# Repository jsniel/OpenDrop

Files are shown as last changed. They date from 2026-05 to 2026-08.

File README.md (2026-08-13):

# OpenDrop

**Low-power wireless irrigation controller**

Open-source autonomous irrigation controller based on an ESP32-C3 Mini.

---

## Description

OpenDrop is a low-power irrigation controller designed for small-scale market gardening and drip irrigation systems.

Originally created to replace manual irrigation valves, it automates watering schedules and reduces repetitive daily work.

Designed for remote plots without access to mains electricity, OpenDrop runs on battery power using deep sleep and pulse-operated latching valves.

The entire project is open-source:

- firmware;
- hardware;
- enclosure;
- wiring;
- documentation.

---

##  Features

- RTC-based irrigation scheduling
- Deep sleep low-power operation
- Local Wi‑Fi configuration portal
- Battery-powered operation
- Relay-controlled irrigation valve
- Configurable watering duration
- Configurable watering cycles
- EEPROM configuration storage
- Fully hackable firmware
- No cloud required

---

## Hardware

### Required

- ESP32-C3 Mini
- DS3231 RTC module
- 2-channel relay module
- MT3608 boost converter
- 18650 Li-ion battery
- AZ Delivery Battery Expansion Shield 18650
- Pulse-operated latching solenoid valve (+5V / -5V polarity reversal)
- 2 push buttons
- LED + resistor
- 1N4007 diode
- 1000 uF capacitors

---

## Wiring

<p align="center">
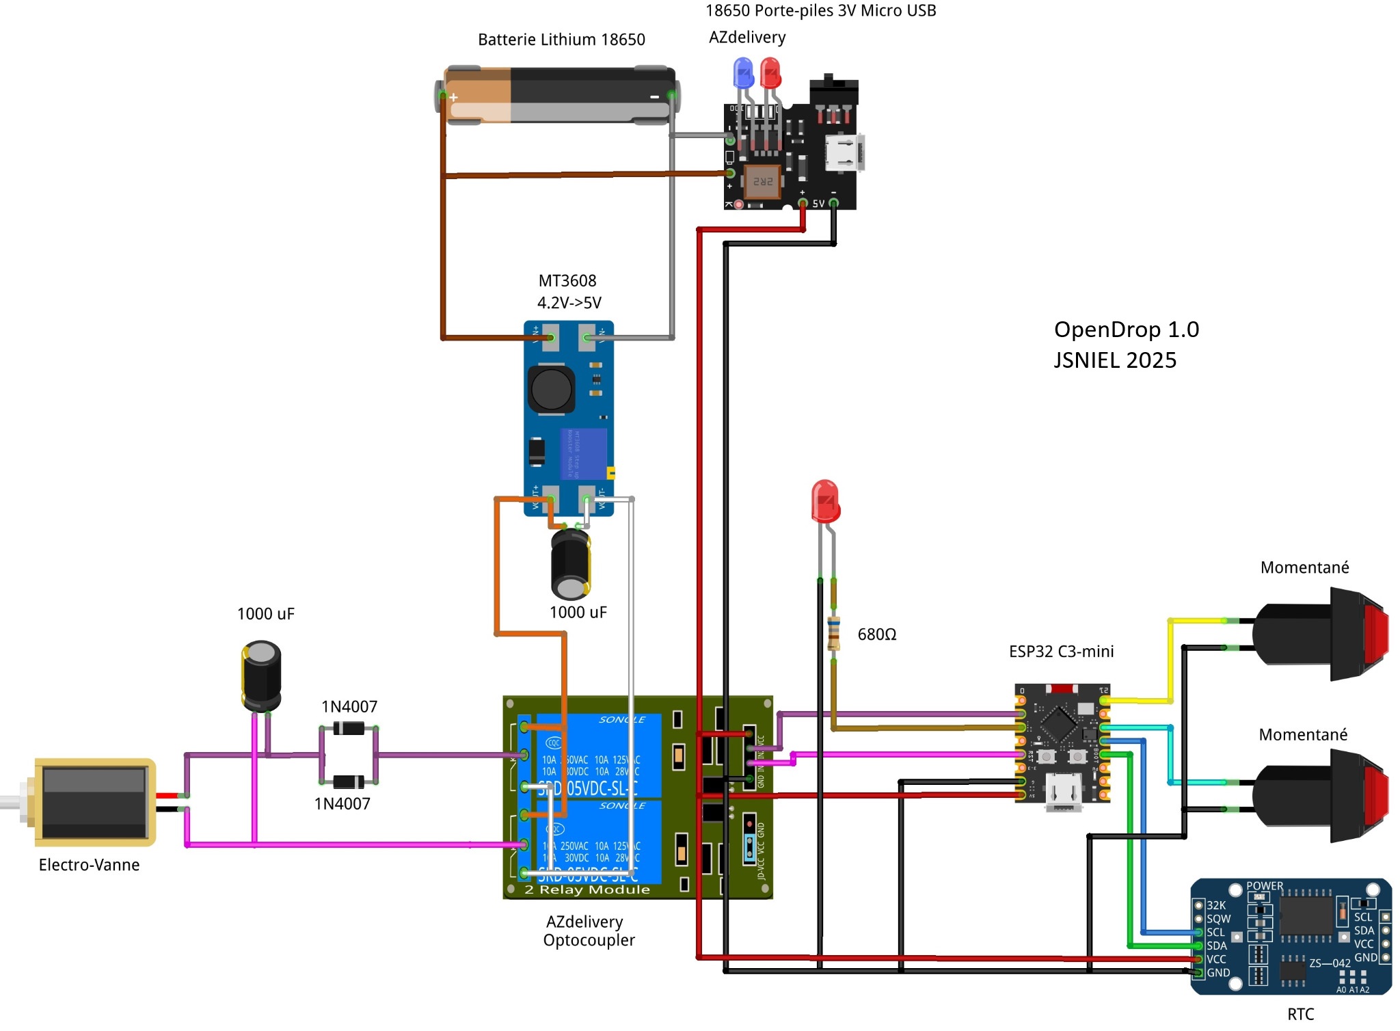
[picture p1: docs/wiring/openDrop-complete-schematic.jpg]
  
</p>
<p align="center">
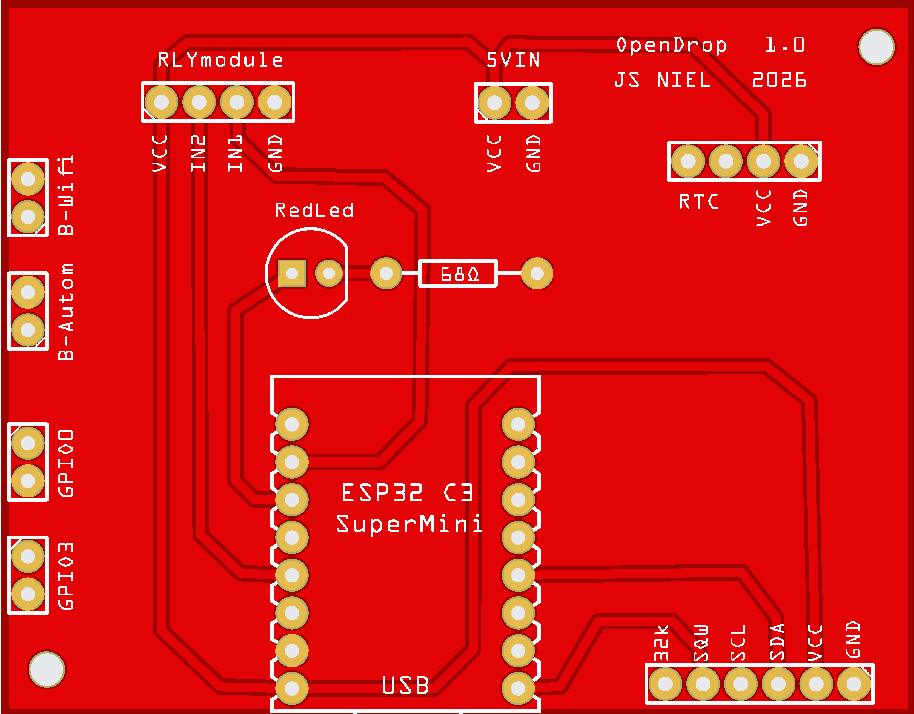
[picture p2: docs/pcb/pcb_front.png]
  
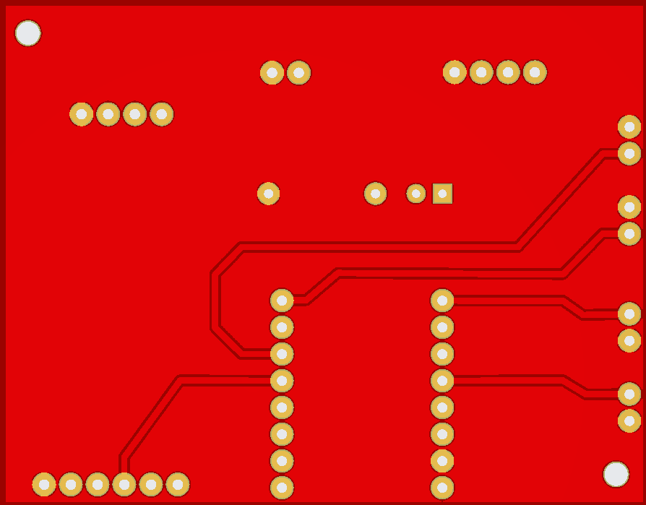
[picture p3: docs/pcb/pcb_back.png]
  
</p>

---

## Prototype Photos

<p align="center">
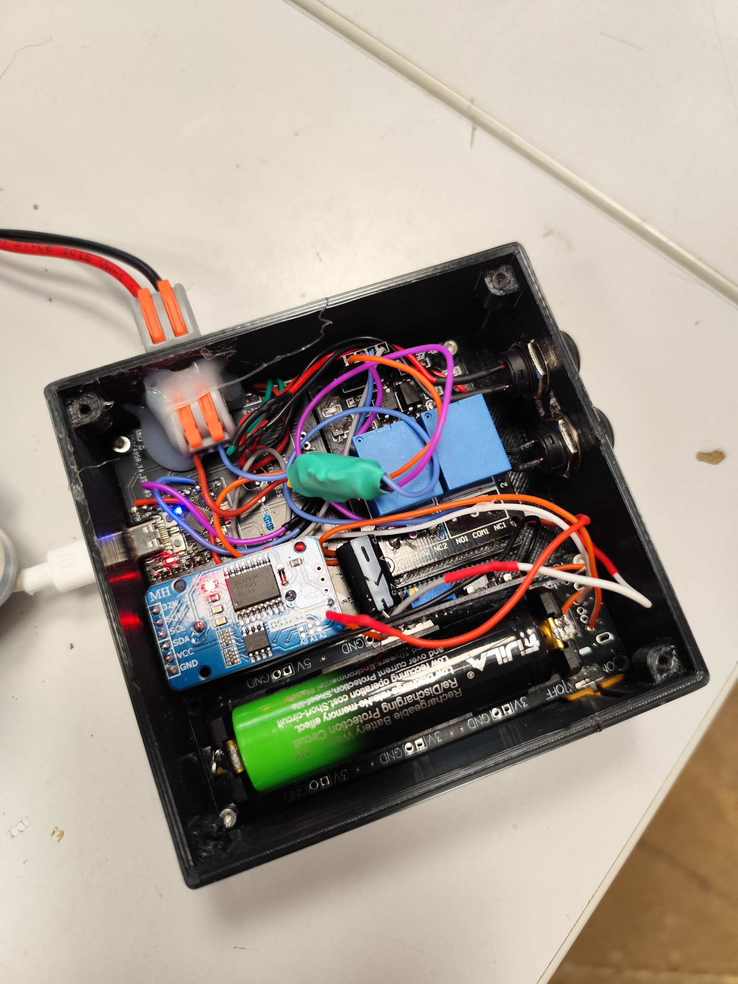
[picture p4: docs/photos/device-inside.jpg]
  
</p>
<p align="center">
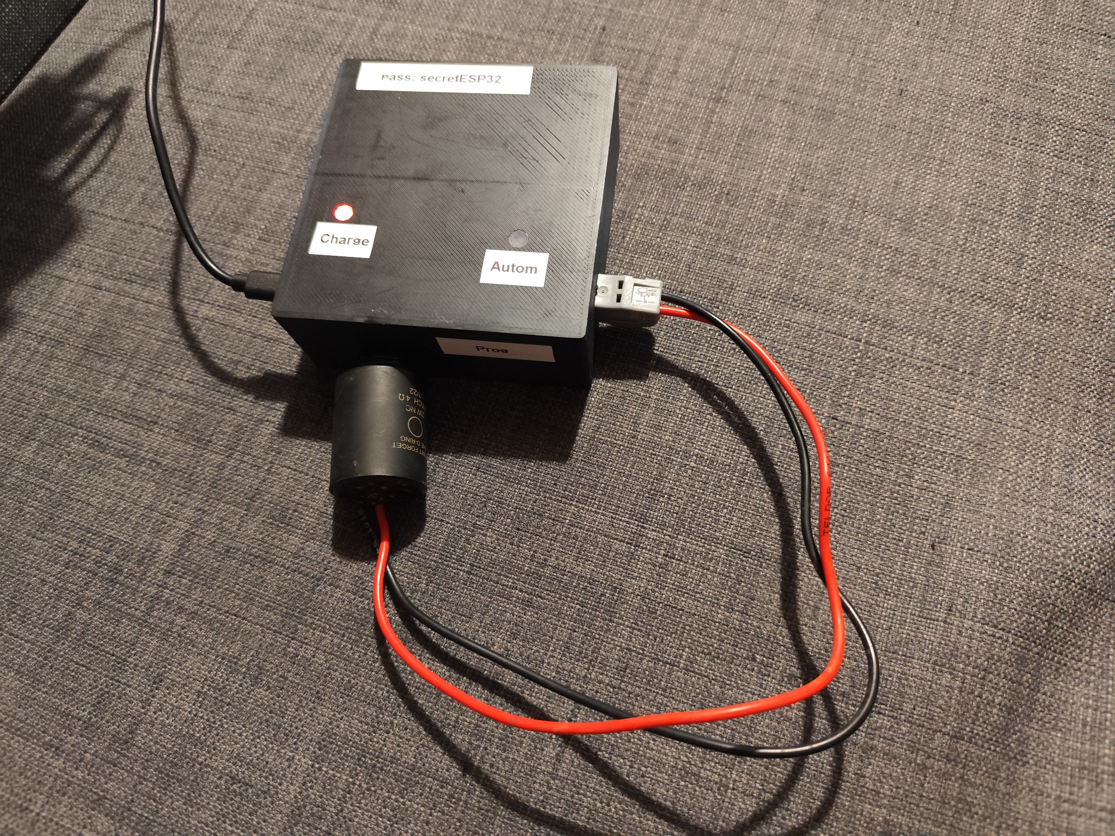
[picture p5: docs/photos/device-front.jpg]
  
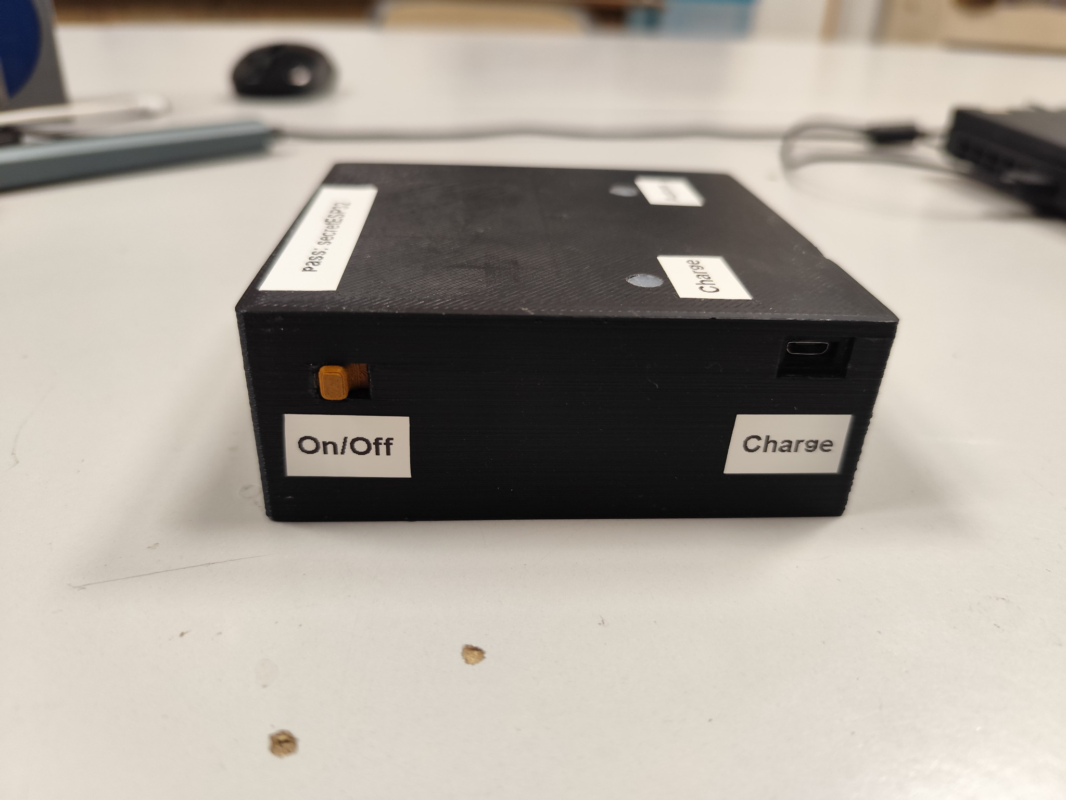
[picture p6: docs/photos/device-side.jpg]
  
</p>

---

## Web Interface

You can:

- Enable or disable automatic watering
- Configure watering time range
- Configure watering duration
- Configure watering cycles per day
- Set RTC time
- Put the controller back to sleep

<p align="center">
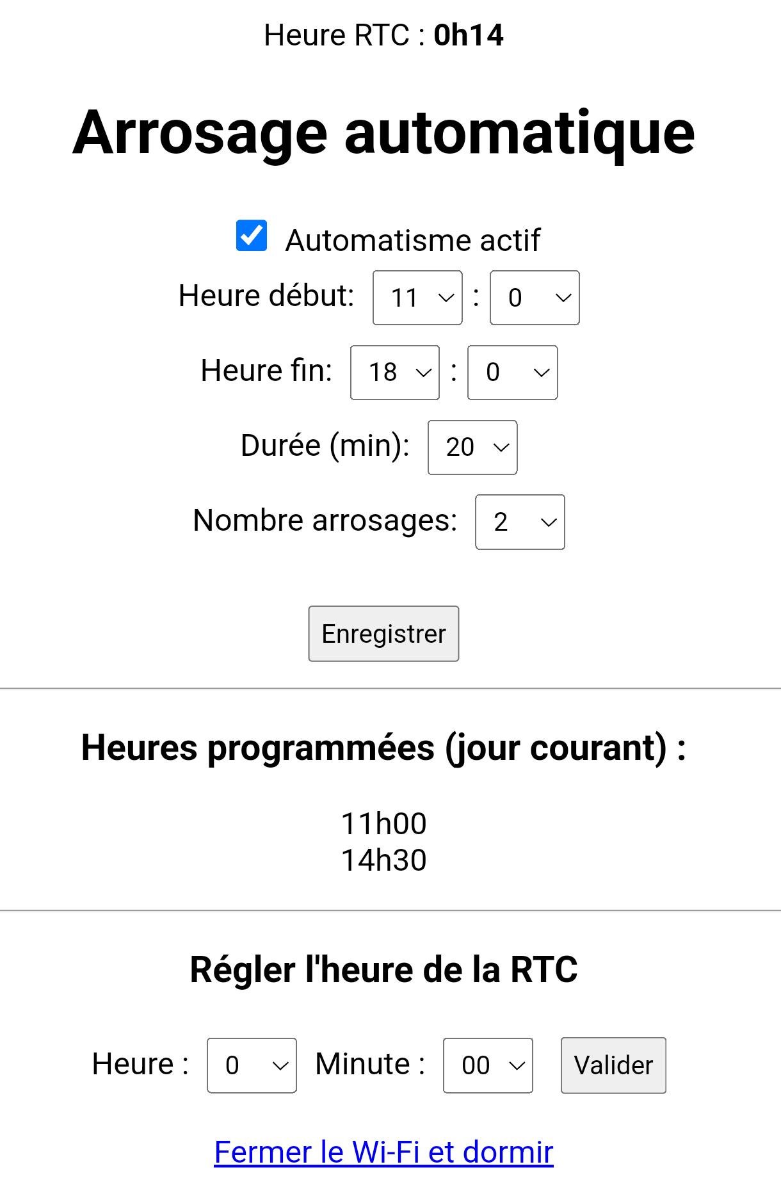
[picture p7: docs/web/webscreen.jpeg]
  
</p>

---

## Buttons and LED

### Wi‑Fi Button

Hold the Wi‑Fi button during wake-up to enable the local Wi‑Fi configuration portal.

Default configuration:

```txt
SSID: arrosageESP
Password: secretESP32
Address: http://192.168.4.1
```

The portal automatically closes after 5 minutes.

---

### Automation Button

Hold the automation button during wake-up to toggle automatic watering ON or OFF.

The state is saved in EEPROM.

---

### LED Behavior

| LED behavior | Meaning |
|---|---|
| Solid ON | Valve open |
| Two short blinks | Automation enabled |
| One long blink | Automation disabled |
| Slow blinking | Wi‑Fi portal active |
| OFF | Deep sleep mode |

---

## Firmware

Location:

```txt
firmware/OpenDrop/OpenDropFW/OpenDropFW.ino
```

---

## Arduino IDE Setup (ESP32‑C3)

### 1. Add ESP32 boards

Open Arduino IDE:

- Go to **File → Preferences**
- In **Additional Boards Manager URLs**, add:

```txt
https://raw.githubusercontent.com/espressif/arduino-esp32/gh-pages/package_esp32_index.json
```

---

### 2. Install ESP32 package

- Go to **Tools → Board → Boards Manager**
- Search: `esp32`
- Install:

```txt
esp32 by Espressif Systems
```

Tested version:

```txt
3.3.5
```

---

### 3. Select board

- Tools → Board → ESP32 Arduino
- Select:

```txt
ESP32C3 Dev Module
```

---

### 4. Required libraries

Install from Arduino Library Manager:

| Library | Tested version |
|---|---:|
| RTClib by Adafruit | 2.1.4 |
| Adafruit BusIO | 1.17.4 |

---

## Usage

### First boot

- Power the device
- Hold the Wi‑Fi button during wake-up
- Connect to the Wi‑Fi access point

---

### Connect

```txt
SSID: arrosageESP
Password: secretESP32
```

Open in browser:

```txt
http://192.168.4.1
```

---

## Known Issues

- No battery level monitoring
- Prototype enclosure is not fully waterproof
- No authentication on the web interface
- No OTA firmware update system

---

## Project Structure

```txt
OpenDrop/
├── firmware/
├── hardware/
├── enclosure/
├── docs/
├── LICENSES/
├── README.md
└── LICENSE
```

---

## Author

**Jean-Sébastien Niel**

GitHub:
https://github.com/jsniel

---

## License

OpenDrop uses separate licenses for firmware and hardware.

### Firmware

GNU General Public License v3.0 or later

```txt
GPL-3.0-or-later
```

### Hardware

CERN Open Hardware Licence Version 2 - Strongly Reciprocal

```txt
CERN-OHL-S-2.0
```

---

## ⚠️ Disclaimer

This project is an experimental DIY open hardware prototype.

OpenDrop switches electrical loads and may be used near water.

Always:

- verify wiring;
- protect electronics from humidity;
- use waterproof connectors;
- verify valve voltage compatibility;
- use appropriate battery protection.

This project is provided without warranty.

---

## Contributing

Pull requests and hardware improvements are welcome.

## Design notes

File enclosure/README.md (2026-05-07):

# Enclosure

3D printable enclosure files for OpenDrop.

Files:
- BOITIER-BOITE.stl
- BOITIER-COUVERCLE.stl
- Switch.stl
- BOITIER.FCStd

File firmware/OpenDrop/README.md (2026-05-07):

# OpenDrop firmware

ESP32-C3 firmware for the OpenDrop low-power wireless irrigation controller.

Firmware by Jean-Sébastien Niel.  
GitHub: https://github.com/jsniel

License: GPL-3.0-or-later

---

## Arduino IDE setup

### 1. Add ESP32 board support

Open Arduino IDE settings or preferences.

Add this URL to **Additional Boards Manager URLs**:

```txt
https://raw.githubusercontent.com/espressif/arduino-esp32/gh-pages/package_esp32_index.json
```

---

### 2. Install ESP32 board package

Open:

```txt
Tools → Board → Boards Manager
```

Search for:

```txt
esp32
```

Install:

```txt
esp32 by Espressif Systems
```

Tested version:

```txt
3.3.5
```

---

### 3. Select board

Select:

```txt
ESP32C3 Dev Module
```

---

## Required libraries

Install from the Arduino Library Manager:

| Library | Tested version | Notes |
|---|---:|---|
| RTClib by Adafruit | 2.1.4 | DS3231 RTC support |
| Adafruit BusIO | 1.17.4 | RTClib dependency |

See also:

```txt
libraries.txt
```

---

## Default access point

```txt
SSID: arrosageESP
Password: secretESP32
IP address: 192.168.4.1
```

Open:

```txt
http://192.168.4.1
```

---

## Buttons

### Wi-Fi button

GPIO: `GPIO10`

Holding the button during wake-up starts the Wi-Fi configuration portal for 5 minutes.

### Automation button

GPIO: `GPIO21`

Holding the button during wake-up toggles automatic watering ON or OFF.

The setting is saved in EEPROM.

If automation is disabled while watering is active, the valve is immediately closed.

---

## LED behavior

| LED behavior | Meaning |
|---|---|
| Solid ON | Valve open |
| Two short blinks | Automation enabled |
| One long blink | Automation disabled |
| Slow blinking | Wi-Fi portal active |
| OFF | Deep sleep |

The LED is configured as active-LOW.

The firmware disables the LED pin before deep sleep to minimize current consumption.

---

## Pin mapping

| Function | GPIO |
|---|---:|
| Wi-Fi mode button | 10 |
| Automation toggle button | 21 |
| Relay open | 4 |
| Relay close | 1 |
| LED | 2 |
| SDA | 8 |
| SCL | 9 |

---

## Deep sleep behavior

Default values in the firmware:

```txt
Button polling interval: 10 seconds
Web configuration window: 5 minutes
Relay pulse duration: 200 ms
```

---

## Web interface routes

| Route | Description |
|---|---|
| `/` | Main configuration page |
| `/save` | Save watering settings |
| `/setrtc` | Set RTC time |
| `/sleep` | Stop Wi-Fi and return to sleep |

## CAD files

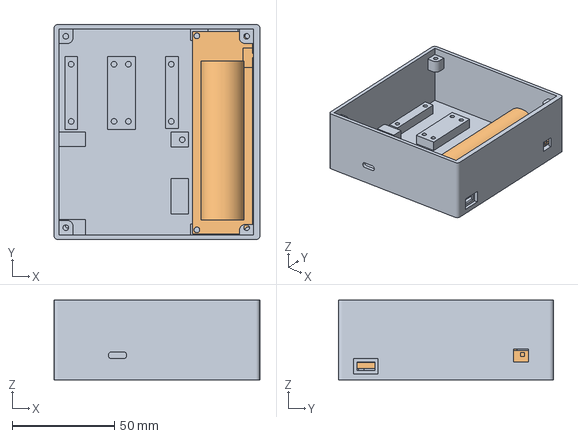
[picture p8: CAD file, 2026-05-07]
enclosure/BOITIER.FCStd
100.9 x 105.5 x 39.0 mm
BOITE
test

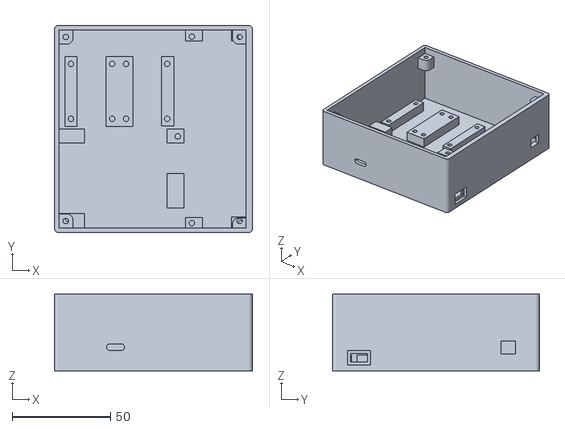
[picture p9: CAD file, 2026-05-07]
enclosure/BOITIER-BOITE.stl
100.9 x 105.4 x 39.0

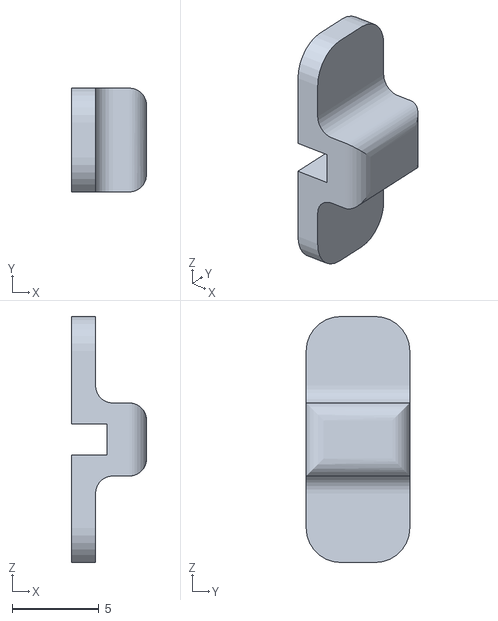
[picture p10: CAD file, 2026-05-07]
enclosure/Switch.stl
4.35 x 6.00 x 14.2

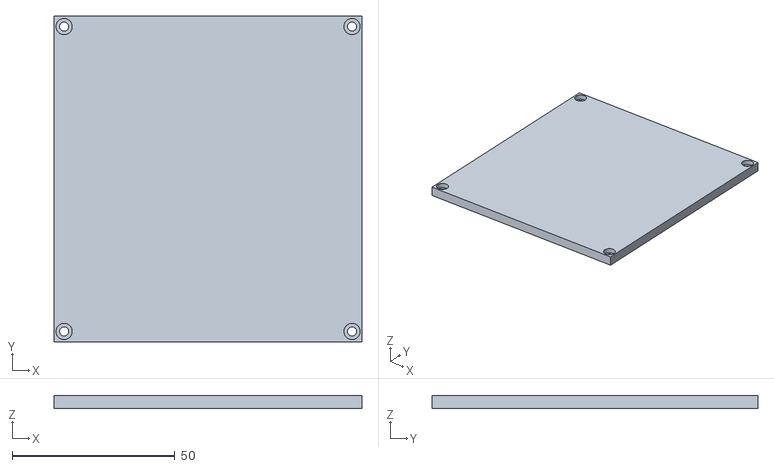
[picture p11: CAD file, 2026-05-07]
enclosure/BOITIER-COUVERCLE.stl
94.7 x 100.1 x 4.00

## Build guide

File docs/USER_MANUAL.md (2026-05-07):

# OpenDrop User Manual

OpenDrop is a low-power autonomous irrigation controller.

Project by Jean-Sébastien Niel.  
GitHub: https://github.com/jsniel

---

## 1. Powering the device

1. Insert a charged 18650 battery.
2. Verify wiring.
3. Power on the system.

---

## 2. Buttons

OpenDrop uses two physical buttons.

---

### Wi-Fi configuration button

Hold the Wi-Fi button while the device wakes up.

The controller periodically wakes from deep sleep to check the buttons.

When the button is detected:

- the Wi-Fi access point starts;
- the configuration web interface becomes available;
- the LED blinks slowly.

Connect to:

```txt
SSID: arrosageESP
Password: secretESP32
```

Then open:

```txt
http://192.168.4.1
```

The Wi-Fi configuration mode automatically stops after 5 minutes.

---

### Automation button

Hold the automation button while the device wakes up.

This toggles automatic watering ON or OFF.

The setting is stored in EEPROM and remains active after reboot or deep sleep.

If automation is disabled while watering is active, the valve immediately closes.

---

## 3. Web interface

The web interface allows:

- enabling or disabling automation;
- setting watering start time;
- setting watering end time;
- setting watering duration;
- setting the number of watering cycles;
- setting the RTC time.

---

## 4. LED feedback

The status LED provides information about the current system state.

| LED behavior | Meaning |
|---|---|
| Solid ON | Valve open |
| Two short blinks | Automatic watering enabled |
| One long blink | Automatic watering disabled |
| Slow blinking | Wi-Fi configuration portal active |
| OFF | Deep sleep mode |

The LED is configured as active-LOW.

Before entering deep sleep, the firmware disables the LED pin to minimize current leakage and battery consumption.

---

## 5. Maintenance

Regularly check:

- battery charge;
- valve operation;
- waterproofing;
- cable condition;
- corrosion on connectors;
- enclosure sealing.

---

## 6. Safety

OpenDrop is a DIY prototype.

Do not expose unprotected electronics to rain, irrigation spray or condensation.

Use waterproof connectors and proper insulation for outdoor installations.

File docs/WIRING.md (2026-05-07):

# Wiring Guide

| GPIO | Function |
|---:|---|
| GPIO10 | Wi‑Fi button |
| GPIO21 | Automation button |
| GPIO4 | Relay open |
| GPIO1 | Relay close |
| GPIO2 | LED |
| GPIO8 | SDA |
| GPIO9 | SCL |

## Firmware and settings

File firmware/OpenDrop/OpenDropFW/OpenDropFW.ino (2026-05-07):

/*
 * ============================================================================
 *  OpenDrop
 *  Low-power wireless irrigation controller
 * ============================================================================
 *
 *  Open-source autonomous irrigation controller based on ESP32-C3.
 *
 *  Features:
 *   - Deep sleep low-power operation
 *   - DS3231 RTC scheduling
 *   - Local Wi-Fi configuration portal
 *   - Relay-controlled irrigation valve
 *   - EEPROM configuration storage
 *   - Battery-powered operation
 *
 *  Project:
 *      https://github.com/jsniel/OpenDrop
 *
 *  Author:
 *      Jean-Sébastien Niel
 *
 *  Firmware License:
 *      GNU General Public License v3.0 or later
 *      SPDX-License-Identifier: GPL-3.0-or-later
 *
 *  Hardware License:
 *      CERN Open Hardware Licence Version 2 - Strongly Reciprocal
 *      SPDX-License-Identifier: CERN-OHL-S-2.0
 *
 *  Copyright (C) 2026 Jean-Sébastien Niel
 *
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
 * ============================================================================
 */
 
#include <WiFi.h>
#include <WebServer.h>
#include <DNSServer.h>
#include <Wire.h>
#include <RTClib.h>
#include <EEPROM.h>
#include "esp_sleep.h"
#include "driver/gpio.h"
#include <time.h>

// ===== Réglages =====
#define BUTTON_POLL_SEC      10        // Intervalle de réveil pour scruter les boutons (tenir le bouton ≤10 s)
#define WEB_WINDOW_MS        300000UL  // 5 min d’AP

// === Broches (inchangées) ===
#define BUTTON_WEB_PIN     10
#define BUTTON_AUTO_PIN    21
#define RELAY_OPEN_PIN      4
#define RELAY_CLOSE_PIN     1
#define LED_PIN             2
#define SDAPIN              8
#define SCLPIN              9

// === EEPROM (inchangée) ===
#define EEPROM_SIZE 16
#define EEPROM_ADDR_ENABLED      0
#define EEPROM_ADDR_START_HOUR   1
#define EEPROM_ADDR_END_HOUR     2
#define EEPROM_ADDR_DURATION     3
#define EEPROM_ADDR_NB_CYCLES    4
#define EEPROM_ADDR_START_MIN    5
#define EEPROM_ADDR_END_MIN      6

// === Réseau/AP ===
const char* ssid = "arrosageESP";
const char* password = "secretESP32";
IPAddress local_IP(192,168,4,1), gateway(192,168,4,1), subnet(255,255,255,0);
WebServer server(80);
DNSServer dnsServer;

// === RTC Externe ===
RTC_DS3231 rtc;
bool rtcOk = false;

// === État & config ===
bool autoEnabled = true;
uint8_t heureDebut = 8, minuteDebut = 0;
uint8_t heureFin   = 20, minuteFin   = 0;
uint8_t dureeArrosage = 10;
uint8_t nombreArrosages = 12;

// === Persistance entre deep sleeps ===
RTC_DATA_ATTR bool    vanneOuverte = false;
RTC_DATA_ATTR uint8_t nextEventType = 0;   // 0 = OUVERTURE, 1 = FERMETURE
RTC_DATA_ATTR time_t  nextEventEpoch = 0;  // epoch de l’événement programmé

// ====== LED active-LOW : helpers ======
constexpr bool LED_ACTIVE_LOW = true;
inline void ledOn()  { digitalWrite(LED_PIN, LED_ACTIVE_LOW ? LOW  : HIGH); }
inline void ledOff() { digitalWrite(LED_PIN, LED_ACTIVE_LOW ? HIGH : LOW ); }

// ================== Utilitaires temps ==================
static inline int toMinutes(int h, int m){ return h*60 + m; }
static inline int spanMinutes(int debut, int fin){
  int span = fin - debut; if (span <= 0) span += 24*60; return span;
}

// Convertit DateTime -> epoch (en se basant sur mktime local)
time_t dtToEpoch(const DateTime& dt){
  struct tm t = {};
  t.tm_year = dt.year() - 1900;
  t.tm_mon  = dt.month() - 1;
  t.tm_mday = dt.day();
  t.tm_hour = dt.hour();
  t.tm_min  = dt.minute();
  t.tm_sec  = dt.second();
  return mktime(&t);
}

// Calcule la prochaine OUVERTURE (epoch) à partir de “now”
time_t computeNextOpenEpoch(const DateTime& now){
  int debut = toMinutes(heureDebut, minuteDebut);
  int fin   = toMinutes(heureFin,   minuteFin);
  int span  = spanMinutes(debut, fin);
  if (nombreArrosages == 0) nombreArrosages = 1;
  float step = (float)span / (float)nombreArrosages;

  for (int dayOffset=0; dayOffset<2; ++dayOffset){
    DateTime base = now + TimeSpan(dayOffset, 0, 0, 0);
    for (int i=0;i<nombreArrosages;i++){
      int mc = (debut + (int)round(i*step)) % (24*60);
      int h = mc/60, m = mc%60;
      DateTime cand(base.year(), base.month(), base.day(), h, m, 0);
      if (dayOffset==0 && cand < now) continue;
      return dtToEpoch(cand);
    }
  }
  return time(nullptr) + 60;
}

// ================== EEPROM ==================
void saveConfig(){
  EEPROM.write(EEPROM_ADDR_ENABLED, autoEnabled);
  EEPROM.write(EEPROM_ADDR_START_HOUR, heureDebut);
  EEPROM.write(EEPROM_ADDR_START_MIN, minuteDebut);
  EEPROM.write(EEPROM_ADDR_END_HOUR, heureFin);
  EEPROM.write(EEPROM_ADDR_END_MIN, minuteFin);
  EEPROM.write(EEPROM_ADDR_DURATION, dureeArrosage);
  EEPROM.write(EEPROM_ADDR_NB_CYCLES, nombreArrosages);
  EEPROM.commit();
}

void loadConfig(){
  autoEnabled     = EEPROM.read(EEPROM_ADDR_ENABLED);
  heureDebut      = EEPROM.read(EEPROM_ADDR_START_HOUR);
  minuteDebut     = EEPROM.read(EEPROM_ADDR_START_MIN);
  heureFin        = EEPROM.read(EEPROM_ADDR_END_HOUR);
  minuteFin       = EEPROM.read(EEPROM_ADDR_END_MIN);
  dureeArrosage   = EEPROM.read(EEPROM_ADDR_DURATION);
  nombreArrosages = EEPROM.read(EEPROM_ADDR_NB_CYCLES);
}

// ================== Relais ==================
void ouvrirVanne(){
  Serial.println("🔁 Ouverture vanne (200 ms)");
  digitalWrite(RELAY_CLOSE_PIN, HIGH);
  digitalWrite(RELAY_OPEN_PIN, LOW);
  delay(200);
  digitalWrite(RELAY_OPEN_PIN, HIGH);
  vanneOuverte = true;
  ledOn(); // LED fixe pendant arrosage
}

void fermerVanne(){
  Serial.println("🔁 Fermeture vanne (200 ms)");
  digitalWrite(RELAY_OPEN_PIN, HIGH);
  digitalWrite(RELAY_CLOSE_PIN, LOW);
  delay(200);
  digitalWrite(RELAY_CLOSE_PIN, HIGH);
  vanneOuverte = false;
  ledOff();
}

// ================== LED feedback ON/OFF ==================
void blinkAutoState() {
  if (vanneOuverte) return; // priorité à l'état "vanne ouverte" (LED fixe)
  if (autoEnabled) {
    // 2 brefs
    for (int i=0;i<2;i++){ ledOn(); delay(120); ledOff(); delay(180); }
  } else {
    // 1 long
    ledOn(); delay(400); ledOff(); delay(300);
  }
}

// ================== Web UI ==================
String htmlPage(){
  String html = "<!DOCTYPE html><html><head><meta charset='UTF-8'><title>Arrosage</title>"
                "<style>body{font-family:sans-serif;text-align:center;}input,select{padding:5px;margin:5px;}</style></head><body>";
  if (rtcOk){
    DateTime now = rtc.now();
    html += "<p>Heure RTC : <strong>"+String(now.hour())+"h"+(now.minute()<10?"0":"")+String(now.minute())+"</strong></p>";
  } else {
    html += "<p style='color:#c00'>RTC non détectée</p>";
  }
  html += "<h1>Arrosage automatique</h1>";
  html += "<form action='/save' method='GET'>";
  html += "<label><input type='checkbox' name='enabled'"+String(autoEnabled?" checked":"")+"> Automatisme actif</label><br>";
  html += "Heure début: <select name='hd'>";
  for (int i=0;i<24;i++) html += "<option value='"+String(i)+"'"+(i==heureDebut?" selected":"")+">"+String(i)+"</option>";
  html += "</select>:<select name='md'>";
  for (int i=0;i<60;i++) html += "<option value='"+String(i)+"'"+(i==minuteDebut?" selected":"")+">"+String(i)+"</option>";
  html += "</select><br>";
  html += "Heure fin: <select name='hf'>";
  for (int i=0;i<24;i++) html += "<option value='"+String(i)+"'"+(i==heureFin?" selected":"")+">"+String(i)+"</option>";
  html += "</select>:<select name='mf'>";
  for (int i=0;i<60;i++) html += "<option value='"+String(i)+"'"+(i==minuteFin?" selected":"")+">"+String(i)+"</option>";
  html += "</select><br>";
  html += "Durée (min): <select name='dur'>";
  int opts[] = {5,10,15,20,30,45,60};
  for (int i=0;i<7;i++) html += String("<option value='")+opts[i]+"'"+(opts[i]==dureeArrosage?" selected":"")+">"+opts[i]+"</option>";
  html += "</select><br>Nombre arrosages: <select name='nb'>";
  for (int i=1;i<=24;i++) html += String("<option value='")+i+"'"+(i==nombreArrosages?" selected":"")+">"+i+"</option>";
  html += "</select><br><br><input type='submit' value='Enregistrer'></form><hr>";

  if (rtcOk && nombreArrosages>0){
    int debutTotal = heureDebut*60 + minuteDebut;
    int finTotal   = heureFin*60 + minuteFin;
    int plageTotale = spanMinutes(debutTotal, finTotal);
    float intervalle = (float)plageTotale / (float)nombreArrosages;
    html += "<h3>Heures programmées (jour courant) :</h3><ul style='list-style:none;padding:0;'>";
    for (int i=0;i<nombreArrosages;i++){
      int minuteCible = (debutTotal + (int)round(i*intervalle)) % (24*60);
      int h = minuteCible/60, m = minuteCible%60;
      html += "<li>"+String(h)+"h"+(m<10?"0":"")+String(m)+"</li>";
    }
    html += "</ul>";
  }

  html += "<hr><h3>Régler l'heure de la RTC</h3>";
  html += "</form><form action='/setrtc' method='GET'>";
  html += "Heure : <select name='h'>";
  for (int i=0;i<24;i++) html += "<option value='"+String(i)+"'>"+String(i)+"</option>";
  html += "</select> Minute : <select name='m'>";
  for (int i=0;i<60;i++) html += "<option value='"+String(i)+"'>"+(i<10?"0":"")+String(i)+"</option>";
  html += "</select> <input type='submit' value='Valider'></form>";
  html += "<p><a href='/sleep'>Fermer le Wi-Fi et dormir</a></p>";
  html += "</body></html>";
  return html;
}

void startWeb(){
  WiFi.mode(WIFI_AP);
  WiFi.softAPConfig(local_IP, gateway, subnet);
  WiFi.softAP(ssid, password);
  dnsServer.start(53, "*", WiFi.softAPIP());

  server.on("/", HTTP_GET, [](){ server.send(200, "text/html", htmlPage()); });

  server.on("/save", HTTP_GET, [](){
    autoEnabled     = server.hasArg("enabled");
    heureDebut      = server.arg("hd").toInt();
    minuteDebut     = server.arg("md").toInt();
    heureFin        = server.arg("hf").toInt();
    minuteFin       = server.arg("mf").toInt();
    dureeArrosage   = server.arg("dur").toInt();
    nombreArrosages = server.arg("nb").toInt();
    saveConfig();
    if (!autoEnabled && vanneOuverte) fermerVanne();
    server.sendHeader("Location","/",true); server.send(302,"text/plain","");
  });

  server.on("/setrtc", HTTP_GET, [](){
    if (rtcOk && server.hasArg("h") && server.hasArg("m")){
      int newH = server.arg("h").toInt();
      int newM = server.arg("m").toInt();
      DateTime now = rtc.now();
      rtc.adjust(DateTime(now.year(), now.month(), now.day(), newH, newM, 0));
    }
    server.sendHeader("Location","/",true); server.send(302,"text/plain","");
  });

  server.on("/sleep", HTTP_GET, [](){
    server.send(200,"text/plain","Fermeture Wi-Fi et dodo...");
    delay(250);
    server.stop(); WiFi.softAPdisconnect(true);
  });

  server.onNotFound([](){ server.sendHeader("Location","/",true); server.send(302,"text/plain",""); });

  server.begin();
}

// ===== Deep sleep helper : éteindre LED vraiment, puis dormir =====
void goDeepSleep(time_t sleepSec){
  // feedback visuel du mode avant dodo (si vanne fermée)
  blinkAutoState();

  // Timer wake
  if (sleepSec < 1) sleepSec = 1;
  esp_sleep_enable_timer_wakeup((uint64_t)sleepSec * 1000000ULL);

  // Éteindre la LED réellement (active-LOW) et passer en entrée pour éviter la lueur
  ledOff();
  pinMode(LED_PIN, INPUT);
  gpio_pulldown_dis((gpio_num_t)LED_PIN);
  gpio_pullup_dis((gpio_num_t)LED_PIN);

  esp_deep_sleep_start();
}

// ================== Planification & Sommeil ==================
void planAndSleep(){
  time_t sleepSec = BUTTON_POLL_SEC;   // par défaut, polling boutons
  time_t nowEpoch = time(nullptr);

  if (autoEnabled){
    if (vanneOuverte){
      // prochaine FERMETURE après la durée (pendant arrosage : pas de polling)
      nextEventType  = 1;
      nextEventEpoch = nowEpoch + (time_t)dureeArrosage*60;
      sleepSec       = (time_t)dureeArrosage*60;
    } else {
      // prochaine OUVERTURE planifiée
      if (!rtcOk){
        nextEventType  = 0;
        nextEventEpoch = nowEpoch + 300; // retry 5 min
        sleepSec       = (BUTTON_POLL_SEC < 300) ? BUTTON_POLL_SEC : 300;
      } else {
        DateTime now = rtc.now();
        nextEventType  = 0;
        nextEventEpoch = computeNextOpenEpoch(now);
        time_t delta   = nextEventEpoch - dtToEpoch(now);
        if (delta < 1) delta = 1;
        sleepSec = (delta < BUTTON_POLL_SEC) ? delta : BUTTON_POLL_SEC;
      }
    }
  } else {
    // Auto OFF : juste polling boutons
    nextEventEpoch = 0;
    nextEventType  = 0;
  }

  Serial.printf("Sleep %ld s (nextType=%u, vanne=%d)\n", (long)sleepSec, (unsigned)nextEventType, (int)vanneOuverte);
  goDeepSleep(sleepSec);
}

// ================== Setup ==================
void setup() {
  Serial.begin(115200);
  delay(50);

  pinMode(RELAY_OPEN_PIN, OUTPUT);
  pinMode(RELAY_CLOSE_PIN, OUTPUT);
  digitalWrite(RELAY_OPEN_PIN, HIGH);
  digitalWrite(RELAY_CLOSE_PIN, HIGH);

  pinMode(LED_PIN, OUTPUT);
  if (vanneOuverte) ledOn(); else ledOff();

  pinMode(BUTTON_WEB_PIN, INPUT_PULLUP);
  pinMode(BUTTON_AUTO_PIN, INPUT_PULLUP);

  Wire.begin(SDAPIN, SCLPIN);
  rtcOk = rtc.begin();
  if (!rtcOk) Serial.println("⚠️ RTC non détectée !");
  else if (rtc.lostPower()) rtc.adjust(DateTime(F(__DATE__), F(__TIME__)));

  EEPROM.begin(EEPROM_SIZE);
  loadConfig();

  // Heure courante (epoch) : si RTC OK, on la convertit en epoch
  time_t nowEpoch = rtcOk ? dtToEpoch(rtc.now()) : time(nullptr);

  // 1) Lire boutons (maintenus) juste au réveil (polling)
  bool webHeld  = (digitalRead(BUTTON_WEB_PIN)  == LOW);
  bool autoHeld = (digitalRead(BUTTON_AUTO_PIN) == LOW);

  if (webHeld){
    Serial.println("WEB maintenu → AP 5 minutes");
    startWeb();
    unsigned long t0 = millis();
    while (millis() - t0 < WEB_WINDOW_MS){
      server.handleClient();
      dnsServer.processNextRequest();
      // LED clignote lentement pendant l’AP
      if (((millis()/500)%2)==0) ledOn(); else ledOff();
      delay(10);
    }
    server.stop(); WiFi.softAPdisconnect(true);
    if (vanneOuverte) ledOn(); else ledOff();
    planAndSleep();
  }

  if (autoHeld){
    Serial.println("AUTO maintenu → toggle ON/OFF");
    autoEnabled = !autoEnabled;
    saveConfig();
    if (!autoEnabled && vanneOuverte) fermerVanne();
    planAndSleep();
  }

  // 2) Exécuter une action due (si programmée)
  if (autoEnabled && nextEventEpoch > 0){
    if (!vanneOuverte && nextEventType==0 && nowEpoch >= nextEventEpoch){
      // OUVERTURE due
      ouvrirVanne();
      // enchaîne vers la FERMETURE après dureeArrosage (pas de polling)
      nextEventType  = 1;
      nextEventEpoch = nowEpoch + (time_t)dureeArrosage*60;
      goDeepSleep((time_t)dureeArrosage*60);
    }
    if (vanneOuverte && nextEventType==1 && nowEpoch >= nextEventEpoch){
      // FERMETURE due
      fermerVanne();
      // planifier la prochaine OUVERTURE
      if (rtcOk){
        DateTime now = rtc.now();
        nextEventType  = 0;
        nextEventEpoch = computeNextOpenEpoch(now);
      } else {
        nextEventType  = 0;
        nextEventEpoch = nowEpoch + 300; // RTC absente → retry 5 min
      }
      planAndSleep();
    }
  }

  // 3) Rien de spécial → planifier et dormir (avec polling)
  planAndSleep();
}

void loop(){ /* tout est géré dans setup() avant de redormir */ }

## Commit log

2026-05-07 Fist commit
    [BOITIER-BOITE.stl, BOITIER-COUVERCLE.stl, BOITIER.FCStd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]
2026-08-13 add pcb
    [PCB-Fritzing.fzz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]
